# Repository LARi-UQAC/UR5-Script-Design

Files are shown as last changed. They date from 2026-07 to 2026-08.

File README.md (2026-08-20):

# Sponsor
Ask for my book (French version): Vibe Design. 30$ contribution via:





# UR5-Script-Design

Tooling around the ISO/COLIPA cosmetic-spread protocol executed on a Universal Robots
UR5 (PolyScope 3.11.0.82155, CB3 controller) with a RobotIQ FT-300 force/torque sensor
and a 2F-85 gripper holding a silicone hemispheric finger.

Full architecture (package layout, coordinate-frame invariants, extension rules) lives in
[ARCHITECTURE.md](ARCHITECTURE.md). This file is the practical entry point: what the
project does, how to install it, and how to run it.

## What is in this repository

Two cooperating Python tools plus the generated on-robot artifacts:

- **`design/`** - interactive design UI (matplotlib) to tune the 6 spreading cycles
  (3 boustrophedon + epicycloid, 3 linear) on a 50x50 mm plate, then export the
  trajectory as `etalement.script` (URScript) and/or `etalement.urp` (PolyScope XML). A
  Paramètres button opens a settings window covering the protocol's tunable variables;
  operator overrides are kept in `etalement_settings.json` (gitignored, specific to one
  workstation and one trial), with a versioned example at
  `etalement_settings.example.json`. The configuration of the trial of record is a separate,
  versioned file, `etalement_trial.json`, from which `--export-trial` regenerates
  `etalement.script` byte for byte.
- **`ur5_sim/`** - offline validator and replay. Parses `etalement.script`, runs
  sequential IK against a UR5 model, reports failures, and (with `--visualize`) renders
  the robot in Swift (WebGL) alongside matplotlib panels (XYZ vs time, XY trail, IK
  branch selector, test-surface overlay). It can also present itself on loopback as a
  UR5 CB3 RTDE server, so [datalogger/](datalogger/)'s fallback monitor can be exercised
  end to end with no robot present (`--emulate`, headless; `--visualize`, driven by the
  viewer's START / PAUSE / STOP). See [ARCHITECTURE.md](ARCHITECTURE.md), section 8.

## Export options

Today the exporter produces one pair of artifacts:

| File | Content |
|---|---|
| `etalement.script` | URScript program for the real robot: 6 spread cycles, `force_mode(...)` regulating 6 N along Z during contact strokes, no gripper actuation (passive finger support). |
| `etalement.urp` | Same program packaged as PolyScope XML, loadable directly on the pendant. |

`ur5_sim` always validates and replays `etalement.script`; nothing in the simulator
depends on any other export target.

A second, additive export option is planned (tracked in
[issue #6](https://github.com/LARi-UQAC/UR5-Script-Design/issues/6), full design in
[docs/superpower/plans/plan_acq_datalogger.md](docs/superpower/plans/plan_acq_datalogger.md)):
`etalement_acq.script` / `etalement_acq.urp`, the same spread program with a 50 Hz TCP
force/pose data logger attached (background thread on the robot, CSV written to the USB
key once the run completes). It does not replace or modify `etalement.script` /
`etalement.urp`; both pairs will keep being generated side by side, and the simulator
keeps using the plain `etalement.script`.

A second, fully independent fallback tool is **implemented** in
[datalogger/](datalogger/) (issue
[#7](https://github.com/LARi-UQAC/UR5-Script-Design/issues/7), design in
[docs/superpower/plans/plan_rtde_fallback_monitor.md](docs/superpower/plans/plan_rtde_fallback_monitor.md)):
`rtde_fallback_monitor.exe`, a standalone statically compiled C executable run from
`cmd.exe` on a lab computer wired to the same isolated VLAN. It passively reads the
robot's RTDE stream and writes its own CSV with automatic per-run file boundaries, driven
by the `runtime_state` field carried in that same stream (no Python, no PowerShell, no
install of any kind on that machine). It is read-only toward the robot. Neither the main
path nor this fallback depends on the other; build and deployment procedure in
[datalogger/README.md](datalogger/README.md), which also covers testing it locally
against `ur5_sim`'s RTDE emulator, with no lab network and no robot.

## Dependencies

Python 3.13, isolated in a local `.venv` (see [requirements.txt](requirements.txt)):
`numpy`, `scipy`, `matplotlib`, `roboticstoolbox-python`, `spatialmath-python`,
`spatialgeometry`, `swift-sim>=1.1.0`, `websockets<13`, `pyright`, `pip-audit`.

```bash
python -m venv .venv
.venv\Scripts\activate
pip install -r requirements.txt
```

Two pinning constraints to respect (details and file paths in `requirements.txt`):

- `swift-sim==1.1.0` requires `websockets<13`; keep this project's `.venv` isolated from
  any global environment that needs `websockets>=13` (for example an LLM SDK).
- `roboticstoolbox-python==1.1.1` on Python 3.13 with `numpy>=2` needs two small in-place
  patches (`DistanceTransformPlanner.py`, `xacro/xmlutils.py`), and `swift-sim` on
  Windows needs a local patch to its `/retrieve/<path>` handler so UR5 meshes load in
  the browser. Apply once after `pip install`; see the header comment of
  `requirements.txt` for the exact patch locations.

Validate the installed dependencies with `pip-audit -r requirements.txt` before any
release.

## Starting the software

Quickest path on Windows, an interactive menu that activates `.venv` automatically:

```bash
.\validate.bat
```

Menu options: kinematic check (target or identity anchor), 3D visualizer (Swift +
matplotlib), design UI alone, design UI and viewer started together, or (options 7-8)
the RTDE emulator alone with the fallback monitor, and a check of its recorded CSV.
Options 3-4 and 7 also start `datalogger/rtde_fallback_monitor.exe` in its own window
when the `.exe` has been built, so a trial run can be cross-checked against the same
loopback stream with no extra step.

Equivalent manual commands:

```bash
# Offline check (parse + IK, no GUI)
python -m ur5_sim --check

# Full visualizer (Swift 3D + matplotlib panels; RTDE emulator served by default)
python -m ur5_sim --visualize
python -m ur5_sim --visualize --no-rtde-serve   # without the emulator socket

# RTDE emulator alone, headless, no GUI and no robot (see ARCHITECTURE.md section 8)
python -m ur5_sim --emulate --runs 2 --pause-at 30
python -m ur5_sim --verify-csv auto             # check the newest recorded CSV

# Design UI (also re-exports etalement.script and .urp)
python ur5_etalementv6.py
python ur5_etalementv6.py --export        # write etalement.script
python ur5_etalementv6.py --export-urp    # write etalement.urp
python ur5_etalementv6.py --no-show       # headless
python ur5_etalementv6.py --export --force  # overwrite a hand-edited output file
python ur5_etalementv6.py --export-trial --no-show --force
                                          # regenerate the trial of record
```

The design window's Paramètres button opens the settings editor described below. The
Sortie field next to Exporter URScript names the output file (default `etalement`), so a
trial variant can be produced without touching the reference `etalement.script`. Settings
persist to `etalement_settings.json` at the repo root (gitignored, specific to one
workstation and one trial); a versioned example lives at
`etalement_settings.example.json`. Both `--export` and `--export-urp` (and the equivalent
Enregistrer/Exporter buttons in the settings window) refuse to overwrite an output file
whose content has drifted from the last recorded export - a `.urp` retouched by hand on
the pendant, for instance - unless `--force` is passed.

Every generated file opens with a "RECETTE DE REPRODUCTION" header stating what produced
it: how many cycles, and for each one its type, its waypoint count and its label, then any
setting that differs from the `design/params.py` defaults, then a short fingerprint. The
header deliberately carries no date. A timestamp would make each export differ from the
last for no reason anyone cares about, and git already records when a file changed; what
was missing was what the file was made of.

The committed `etalement.script` is the trial of record, the program that ran on the robot.
It comes from the interface export path rather than the headless one, and the configuration
that produced it is written down in the versioned `etalement_trial.json`, so
`--export-trial` reproduces it byte for byte. Do not confuse that file with
`etalement_settings.json`, which holds one workstation's overrides and stays gitignored.

## Settings

The Paramètres button opens a window with five tabs, generated from a single metadata
table so a new field never needs its own hand-written row: Force (target Z force and the
`force_mode` deviation limits), Sondage (Z-probe timing, plus the parked 3-point probe
fields), Mouvement (URScript accelerations, phase speeds, blend radius, circular waypoint
density), Surface (plate size, transit and retreat heights, cycle durations and counts),
and Calibration (robot origin, base rotation, `P_REF`, and the four TCP tool-length
offsets). Each row shows the field next to its hard-coded default and valid range, so a
saved override stays legible against the protocol reference in `design/params.py`.

Two fields stay read-only on every tab: `urscript_max_tcp_speed` and `urscript_max_bytes`
are PolyScope controller limits, not preferences, and letting the operator edit them would
misrepresent what the real controller enforces. The Calibration tab is locked behind an
explicit "Deverrouiller la calibration" checkbox with a confirmation dialog, because its
fields move the robot's anchor in the world rather than tune the spreading protocol; a
session always reopens locked, since nothing there is meant to persist by accident.
`tcp_z` is
computed from the four tool-length fields above it (FT-300, coupling, 2F-85 gripper,
silicone finger) and cannot be edited on its own.

The Sondage tab's dropdown still lists a `plane3` probing mode, but `validate()` refuses
that value when Appliquer is clicked, and the four fields `plane3` alone would need
(approach height, tilt limit, retry count, probe points) stay grayed out regardless of the
selected mode: the 3-point probe is parked, incorrect as implemented (fixed in Z, no
tilt), and its rework is separate future work (see [ARCHITECTURE.md](ARCHITECTURE.md),
section 6).

Réinitialiser resets either the current tab or the whole window to the `design/params.py`
defaults. Deleting `etalement_settings.json` has the same effect for the whole file: the
settings layer falls back to those defaults whenever the file is absent or unreadable.

## Tests

Stdlib `unittest`, no pytest:

```bash
python -m unittest discover -s tests -p "test_*.py"
```

Among that suite, `test_force_model.py`, `test_rtde_server.py`, `test_rtde_headless.py`,
`test_emulate_cli.py`, `test_viewer_rtde_wiring.py` and `test_verify_csv.py` cover the
RTDE emulator - loopback only, GUI-free, no robot needed. Full detail in
[ARCHITECTURE.md](ARCHITECTURE.md), section 10.

One exception, in C: the RTDE fallback monitor in [datalogger/](datalogger/) is a C tool,
because the lab computer it runs on has no Python and nothing can be installed there. Its
tests are C as well, so they call the tool's own functions directly instead of shelling
out, and they are not collected by the discovery above. Run them with MinGW-w64 `gcc` on
`PATH`:

```bash
datalogger\tests\build_and_run_tests.bat
```

## Where to go next

- [ARCHITECTURE.md](ARCHITECTURE.md) for the package layout, the three coordinate
  frames every new pose must travel through, the CB3 URScript generation constraints,
  the force-mode kinematic surrogate, and the rules for extending the project.
- [CLAUDE.md](CLAUDE.md) for the same material kept as an operational summary.

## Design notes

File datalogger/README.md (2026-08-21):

# datalogger

Data-acquisition tooling for the ISO/COLIPA cosmetic-spread trials on the UR5 CB3.

Two independent paths record the same variables. Both are required; neither replaces the
other, and they share no code, no process and no file, so a fault in one cannot corrupt the
output of the other.

| Path | Where it runs | Output | Status |
|---|---|---|---|
| On-robot logger (main) | Robot controller + USB key | `ACQ_log_*.csv` | Implemented, in [`../onrobot/`](../onrobot/README.md) - Python, not part of this folder |
| RTDE fallback monitor | Lab computer, over the network | `ACQ_rtde_*.csv` | Implemented, described below |

**This folder is C only.** It holds one executable, which records what the robot transmits
on its RTDE port, plus its build script and its C test harness. The on-robot acquisition
path is Python and lives in [`../onrobot/`](../onrobot/README.md); the two share the seven
CSV columns and nothing else - no code, no process, no file.

---

## RTDE fallback monitor

`rtde_fallback_monitor.exe` reads the robot's Real-Time Data Exchange stream from a second
machine and writes one CSV per robot program run. It touches nothing on the controller: no
URScript program, no USB key, no installed software. Design and rationale are in
[`plan_rtde_fallback_monitor.md`](../docs/superpower/plans/plan_rtde_fallback_monitor.md).

The tool is **read-only toward the robot**. It opens one outbound TCP connection, requests
an output recipe and reads packets. The RTDE input path is never used, so no motion
command, no register write and nothing else that could disturb a running program can leave
this tool. It is safe to leave connected during a trial and safe to run at the same time as
the on-robot logger, which is how the two sources cross-validate each other.

### What it records

`timestamp`, `actual_TCP_pose`, `actual_TCP_force` and `runtime_state`, written as the
seven columns shared with the on-robot path:

```
Time,ForceX,ForceY,ForceZ,PoseX,PoseY,PoseZ
```

Only the translational components are kept (no rotations, no torques), at a 50 Hz cadence.

### Automatic file boundaries, no operator action

`runtime_state` travels in the same stream as the measurements, so the tool finds its own
file boundaries with no polling, no second connection and no manual "start a new file"
step:

| Transition | Action |
|---|---|
| `STOPPED` to `PLAYING` | Open a new `ACQ_rtde_*.csv` |
| `PAUSING`, `PAUSED`, `RESUMING` | Nothing: same trial, same file, samples keep appending |
| anything to `STOPPED` | Finalize and close the file |

Starting the tool while a program is already running also opens a file, rather than waiting
for the next program start.

If two trials land in the same wall-clock second, the second file gets a `_1`, `_2` suffix.
No trial can overwrite another: past 99 same-second collisions (bare name plus `_1`
through `_99` all taken), the tool refuses to open a new file rather than reuse one of
those names, and reports the exhaustion on the console.

---

## Build

Needs MinGW-w64 `gcc` (`x86_64-w64-mingw32`). Build on any normal networked machine; the
lab computer needs nothing installed.

```
datalogger\build.bat
```

or directly:

```
gcc -O2 -static -Wall -Wextra -o rtde_fallback_monitor.exe rtde_fallback_monitor.c -lws2_32
```

`-static` links the MinGW C runtime in, so the result is a single self-contained 64-bit
executable. Confirmed dependencies are `KERNEL32.dll`, `msvcrt.dll` and `WS2_32.dll` only,
all core Windows libraries present on every Windows 10 install.

## Test

```
datalogger\tests\build_and_run_tests.bat
```

Builds and runs the harness (283 checks; non-zero exit on any failure). No robot, no
network, no framework. It covers big-endian decoding against known byte sequences, every
ordered `runtime_state` transition pair, the decimation cadence, the CSV format, and an
integration layer that replays the RTDE handshake from a fake server on `127.0.0.1`:
one-run/one-file, pause not splitting a file, two runs producing two files, a reset
connection leaving the partial file intact, a `NOT_FOUND` recipe field aborting before any
data is logged, and the protocol-version-1 fallback.

Run it before any on-robot step.

```
datalogger\tests\build_and_run_tests.bat --repeat 20
```

Builds once, then runs the harness 20 times and requires every run to produce the same exit
code and the same summary line as the first; this is how the fake server's handshake is
checked to be deterministic (F16), rather than merely passing once. A run that diverges has
its full stdout kept as `mismatch_run_<N>.out` next to the harness, named on the console:
without it the gate would report that something differed and then delete the only record of
what it was. Those files are gitignored and are deleted at the start of the next
`--repeat` run.

---

## Testing locally against `ur5_sim`

Before wiring the VLAN and the real robot, the whole socket path can be exercised on one
development machine, loopback only, with no robot present: `ur5_sim` (design in
[`plan_rtde_emulator.md`](../docs/superpower/plans/plan_rtde_emulator.md)) can present
itself as a UR5 CB3 RTDE server on `127.0.0.1:30004`, the same handshake, recipe and byte
layout this monitor expects from the real controller. See
[ARCHITECTURE.md](../ARCHITECTURE.md), section 8, for the full wire contract.

Two terminals, no VLAN, no static IP (both from the repo root):

```
# Terminal 1 - the monitor, pointed at loopback instead of the robot; sim_runs is
# where --verify-csv auto looks first
datalogger\rtde_fallback_monitor.exe 127.0.0.1 30004 datalogger\sim_runs

# Terminal 2 - the emulator, headless, two consecutive runs
python -m ur5_sim --emulate --runs 2
```

`ur5_sim --visualize` also serves the emulator by default, driven from the viewer's
START / PAUSE / STOP instead of `--runs`; pass `--no-rtde-serve` to turn it off.
`.\validate.bat` wraps both terminals into one step: options 3, 4 and 7 start the monitor
automatically (skipped with a warning if `rtde_fallback_monitor.exe` has not been built
yet), and option 8 runs `python -m ur5_sim --verify-csv auto` against whatever the monitor
just recorded, in `datalogger\sim_runs\`.

A CSV recorded from the emulator is not a lab trial, and its header says so: any peer
connecting from a loopback address gets a `# WARNING: SIMULATED SOURCE - ur5_sim RTDE
emulator, not robot data` line, right after `Robot RTDE Endpoint`, so a loopback recording
can never be mistaken for one filed from the real UR5 at `192.168.4.38`. `--verify-csv`
reads the same header and echoes the note back in its own report.

---

## Deployment procedure

1. **Build** on a machine that has `gcc` (need not be the lab computer): `build.bat`.
2. **Wire** the lab computer to IE5000 switch port 4 (VLAN 4). Wired only: the site's
   `laimi-robot` Wi-Fi conflicts with other local networks and is not a supported path.
3. **Set the static IP** `192.168.4.14/24` on that interface. There is no DHCP on this
   VLAN.
4. **Confirm the subnet mask** against the switch's VLAN 4 configuration. `/24` is the
   working assumption, consistent with both addresses, but it was never confirmed against
   the switch; adjust the prefix length if VLAN 4 uses something else.
5. **Confirm reachability** before touching RTDE:
   ```
   ping 192.168.4.38
   ```
6. **Copy only** `rtde_fallback_monitor.exe` to the lab computer. Nothing else ships: no
   DLL, no installer, no source.
7. **Run it** from `cmd.exe`, from the folder where the CSVs should land:
   ```
   rtde_fallback_monitor.exe 192.168.4.38 30004 .
   ```
   Stop it with Ctrl+C; the file in progress is finalized before it exits.

### First-run SmartScreen prompt

An unsigned executable copied from removable media raises "Windows protected your PC" the
first time it runs. Click **More info**, then **Run anyway**. This is expected once, not a
failure to debug.

## Verifying on the robot

1. Start a trial from the pendant. An `ACQ_rtde_*.csv` appears on its own, with no action on
   the lab computer.
2. Pause and resume from the pendant mid-trial. The file must **not** split in two.
3. Stop the trial. The file closes; the console prints its row count.
4. Start a second trial. A second, distinct file opens automatically.
5. If the on-robot path is also running, confirm both CSVs are plausible and independently
   readable for the same trial. The two sample independently, so this is a cross-check, not
   an equality test.

On the first connection the tool prints the measured inter-packet interval, for example:

```
[RTDE] stream interval 0.0080 s (125.0 Hz), decimating to 50 Hz
```

That line settles the controller's real base output rate, which is not confirmed from
public documentation for this PolyScope build.

---

## CSV format

```
# Robot Model: UR5 CB3
# PolyScope Version: 3.11.0.82155 (20 August 2019)
# Data Source: RTDE fallback monitor (192.168.4.14)
# Robot RTDE Endpoint: 192.168.4.38:30004
# File Creation Date: 2026-08-14
# File Creation Time: 10:15:30
# Target Acquisition Frequency: 50 Hz
# Time Column: RTDE timestamp field, relative to the first sample of this file (s)
# RTDE Timestamp At First Sample: 123456.797000 s (controller uptime)
Time,ForceX,ForceY,ForceZ,PoseX,PoseY,PoseZ
0.000,-0.123456,0.234567,-6.012345,0.412345,-0.298765,0.101234
```

- `Data Source` names the local address of the socket that actually connected to the robot,
  read at run time with `getsockname()`, not a constant: it is `192.168.4.14` above because
  that is the lab computer's static IP from the deployment procedure, but the same binary run
  from a commissioning laptop or the loopback emulator rig names that machine's own address
  instead (`127.0.0.1` on loopback). If the address cannot be read, the field falls back to
  the literal `unknown` rather than a plausible-looking guess. It is independent of
  `Robot RTDE Endpoint` below, which is the peer, always `argv`.
- `Time` is the robot's own RTDE `timestamp`, referenced to the first sample of the file, so
  it starts at `0.000` exactly like the on-robot path's tick time and the two CSVs align
  without any clock conversion. The absolute controller value of that first sample is kept
  in the header, so the offset loses nothing. Three decimals, matching the on-robot path.
- Forces are newtons and poses are metres, six decimals.
- No `Maximum Buffer Size` or `Actual Number of Collected Samples` line: this tool has no
  fixed-size buffer, it streams straight to disk row by row.

### Cadence

The controller streams at its own base rate and the tool imposes the 50 Hz cadence from
each packet's own `timestamp`, so the output is timestamp-exact whatever that base rate
turns out to be. The rule is grid-based, emitting the first packet at or after each 20 ms
boundary. A gap-based rule would give 125/3 = 41.7 Hz on a 125 Hz stream instead of 50 Hz.

## Behavior when things go wrong

| Situation | Behavior |
|---|---|
| Robot unreachable, or not yet powered | Prints the reason, retries every 2 s. Leave it running; it connects when the robot comes up. |
| Controller reboot or cable pull mid-trial | Prints a diagnostic, finalizes the current CSV with every row already written, then reconnects. No truncation, no silent loss. |
| A recipe field unsupported on this build | RTDE answers `NOT_FOUND`; the tool refuses the session and exits rather than decode at wrong offsets and fill a CSV with plausible garbage. |
| Mistyped robot IP | Rejected at startup, before the reconnect loop, so a typo fails fast instead of retrying forever. |

## Notes for maintainers

- **The C source is an exception to this repo's Python-only test convention.** The lab
  computer has no Python and nothing can be installed on it (no internet on that VLAN), so
  the tool is C; its tests are C as well, so they can call its own functions directly rather
  than shell out. They are not part of `python -m unittest discover -s tests`; run
  `datalogger\tests\build_and_run_tests.bat` instead.
- Every multi-byte field is decoded through `read_be_u16` / `read_be_u32` /
  `read_be_double`, never an inline pointer cast. RTDE is big-endian and x86-64 is not; a
  cast would also violate alignment and strict aliasing, since fields sit at arbitrary
  offsets behind a 3-byte header. One place to get right, pinned by known-value tests.
- The tool negotiates RTDE protocol version 2 and falls back to version 1. Version 1 is not
  a degraded mode here: it carries no `output_frequency` field at all, which suits a tool
  that takes whatever the controller streams and imposes its own cadence.
- The tool is standalone. It reads and writes nothing belonging to `etalement.script`,
  `etalement.urp`, `ur5_sim` or the design UI.

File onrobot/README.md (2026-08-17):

# onrobot

The on-controller acquisition path: record TCP force and TCP position at 50 Hz during an
ISO/COLIPA spread trial, one uniquely named CSV per trial, written to the robot's USB key.

Everything here runs without a second machine. The independent fallback path, a C recorder
reading the robot's RTDE stream from a lab computer, is in [`../datalogger/`](../datalogger/README.md);
the two share the seven CSV columns and nothing else - no code, no process, no file - so a
fault in one cannot corrupt the other's output. Design and rationale:
[`plan_acq_datalogger.md`](../docs/superpower/plans/plan_acq_datalogger.md).

| File | Where it runs | Role |
|---|---|---|
| `acq_logger_daemon.py` | Robot controller, from the USB key | Loopback TCP server on port 50100 receiving samples from `etalement_acq.script`, plus an FT-300 reader on port 63351. Buffers in RAM for the whole trial, writes the CSV on `STOP`. |
| `urmagic_acqlogger.sh` | Robot controller, as root | UR magic file: the controller runs it when the key is inserted, it launches the daemon and returns. |
| `acq_emulator.py` | Development machine only | Fake FT-300 plus a fake robot replaying the real poses of `etalement.script`. Never copied to the robot. |

The URScript half is not here: `design/export.py` emits `etalement_acq.script`, the original
6-cycle program plus a `data_logger` thread. The original `etalement.script` is untouched and
remains what `ur5_sim` validates.

## Why the buffer is in the daemon and not in URScript

URScript on a CB3 has no file API, no date function, no `list_append`, no list slicing, and a
practical list size in the hundreds. The 11700-sample buffer and the file write are therefore
impossible in the robot program as originally specified. They live in a Python process on the
same controller; the robot program only opens a socket and sends one list per sample. During
motion there is zero USB I/O.

## Deployment

1. **Copy three files to the root of the USB key**: `acq_logger_daemon.py`,
   `urmagic_acqlogger.sh`, and the exported `etalement_acq.script`. Nothing else. The daemon
   imports only the standard library, so nothing is installed on the controller.
2. **Read `urmagic_acqlogger.sh` before the first insertion.** The controller runs it as
   root. It is short and every line is commented for exactly that reason.
3. **Insert the key** into the pendant. The daemon starts and writes its log beside itself on
   the key. Check that log before trusting a trial: the first FT-300 sample is printed raw,
   which is how a wire-format mismatch is caught before it silently lands in a CSV column.
4. **Load `etalement_acq.script`** in PolyScope and run it. If the daemon is not answering,
   the program aborts with a popup **before the robot moves**.
5. **At the end of the program**, a popup reports `OK ACQ_log_<date>_<time>.csv (N samples)`
   or the daemon's error text. On error the samples stay in the daemon's RAM.
6. **Remove the key only between trials**, never during one.

Each run produces a new timestamped file; a same-second collision appends `_1`, `_2`. No
overwrite is possible.

## CSV

```
# Robot Model: UR5 CB3
# PolyScope Version: 3.11.0.82155 (20 August 2019)
# File Creation Date: YYYY-MM-DD
# File Creation Time: HH:MM:SS
# Target Acquisition Frequency: 50 Hz
# Maximum Buffer Size: 11700
# Actual Number of Collected Samples: N
Time,ForceX,ForceY,ForceZ,PoseX,PoseY,PoseZ
0.016,-0.082475,0.050368,-6.040525,-0.017788,0.586142,0.050004
```

`Time` is robot tick time in seconds, from the controller's own 8 ms thread counter. It steps
0.016 and 0.024 alternately, because 20 ms is 2.5 ticks and cannot be produced exactly: the
thread alternates 2 and 3 ticks for a mean of exactly 20.000 ms. Every sample carries its true
tick time, so the analysis is exact even though the spacing alternates. Forces are newtons,
poses metres, both to 6 decimals. Only collected rows are written.

The same seven columns are produced by the RTDE fallback monitor under the `ACQ_rtde_` prefix,
so two recordings of one trial can be compared directly.

## Protocol on port 50100

| Line received | Daemon action | Reply |
|---|---|---|
| `[t,x,y,z]` or `[t,x,y,z,fx,fy,fz]` | append, merging the latest FT-300 triple when the sample carries no force | none |
| unparsable | counted in `n_bad`, ignored | none |
| `[-1.0,n,0.0,0.0]` | counting sentinel: records what the robot says it sent | none |
| `STOP` | write the CSV, fsync, close | `OK <file> <rows>` |
| `STOP` after a write failure | keep the buffer in RAM | `ERR <reason>` |
| `RETRY` | rewrite from the retained buffer | `OK ...` or `ERR ...` |

The sentinel exists because a CB3 cannot build the string `STOP <n>`: PolyScope 3.x has
neither `to_str` nor `str_cat`. The count arrives as a list whose first field is negative,
which no real sample can be, immediately before the literal `STOP`. A disagreement between
that count and the rows received is reported, never corrected: it is the only evidence
available that lines were lost.

## Offline exercise, no robot

Three shells:

```
python onrobot/acq_logger_daemon.py
python onrobot/acq_emulator.py --ft
python onrobot/acq_emulator.py --robot etalement.script --samples 200
```

The third replays the real poses of the exported program at 50 Hz with the same alternating
tick times, ends with the sentinel and `STOP`, and exits non-zero unless the daemon answers
`OK`. `--samples` exercises the buffer cap without waiting four minutes.

## Tests

```
python -m unittest tests.test_acq_logger_daemon -v   # 30 tests, daemon
python -m unittest tests.test_acq_export -v          # 13 tests, emitted script
```

Both are collected by `python -m unittest discover -s tests -p "test_*.py"`, unlike the C
harness of `../datalogger/`. They run offline on Windows: fake sockets, a fake clock, a temp
directory standing in for the USB key. `test_acq_export.py` is the one that matters most for
safety - it proves the acq twin's motion is identical to the original's, pose for pose.

## Known limitations

- **`RETRY` recovers only within the same connection.** If the socket drops before `STOP`,
  the buffered trial is lost with it.
- **The FT-300 wire format is not confirmed** from public documentation for URCap 1.11.0.29.
  The parser follows the documented Robotiq format and the daemon logs one raw sample at
  connect time so a mismatch is visible rather than silently miscolumned.
- **Force and pose are merged, not simultaneous.** The FT-300 streams at 100 Hz and its
  latest triple is attached to each 50 Hz pose, so the worst-case skew is 10 ms.
- **No USB mount detected** falls back to `/tmp` with a warning in the metadata rather than
  losing the trial. The mount point varies across CB3 images, which is why it is detected
  from `/proc/mounts` instead of hardcoded.
- **The controller clock may be wrong** on an isolated network with no NTP. Filenames stay
  unique regardless; only the absolute date is affected.

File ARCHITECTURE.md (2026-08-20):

# Architecture — UR5Script

Reference architecture for the ISO/COLIPA cosmetic-spread tooling (UR5 + RobotIQ FT-300 +
2F-85 holding a silicone hemispheric finger). This file is the context base for the next
improvement: it states what exists, which invariants must survive any change, and where
new work plugs in. It supersedes the older module descriptions in `CLAUDE.md` where they
disagree (the design UI is now the `design/` package; IPC is now UDP).

## 1. System overview

Two cooperating Python tools plus the generated on-robot artifacts:

```mermaid
flowchart LR
    subgraph design["design/ (trajectory design UI)"]
        params[params.py<br/>single source of truth]
        geometry[geometry.py<br/>SE3 + plate_to_robot]
        trajectory[trajectory.py<br/>cycle generators]
        export[export.py<br/>URScript / URP emit]
        app[app.py<br/>matplotlib UI]
        liveipc[live_ipc.py<br/>UDP receiver + overlay]
    end

    subgraph artifacts["Exported artifacts"]
        script[etalement.script<br/>URScript CB3]
        urp[etalement.urp<br/>PolyScope XML]
    end

    subgraph sim["ur5_sim/ (offline validator + replay)"]
        parsing[parsing/urscript.py]
        kin[kinematics/<br/>transforms, ik, ik_multisolve, motion]
        surf[visualization/surface.py<br/>force-mode surrogate]
        viewer[visualization/viewer.py<br/>Swift + matplotlib]
        report[reporting/text_report.py]
        cli[cli.py]
        probe[probe.py<br/>PARKED 3-point probe]
    end

    robot[UR5 CB3 controller<br/>force_mode 6 N on Z]

    app --> export
    export --> script
    export --> urp
    script --> robot
    urp --> robot
    script --> parsing
    parsing --> cli
    cli --> kin
    cli --> surf
    cli --> report
    cli --> viewer
    viewer -- "UDP 127.0.0.1:47811<br/>JSON frame" --> liveipc
    params -.imported by.-> geometry
    params -.imported by.-> simconfig[ur5_sim/config.py]
```

- `design/` is the interactive design UI (entry point kept as `ur5_etalementv6.py`, a
  2-line shim over `design.app.main`). The operator tunes the 6 spreading cycles
  (3 boustrophedon + epicycloid, 3 linear) on a 50x50 mm plate and exports
  `etalement.script` / `etalement.urp`.
- `ur5_sim/` parses the exported URScript, replays it through sequential IK against
  `roboticstoolbox.models.UR5`, applies a kinematic surrogate of the force mode, and
  reports failures (`--check`) or renders the run (`--visualize`, Swift WebGL +
  matplotlib panels).
- The real robot regulates 6 N along Z with `force_mode(...)` during contact strokes;
  the simulator has no physics and emulates this geometrically (section 5).

## 2. Package layout and responsibilities

### `design/` — trajectory design

| Module | Responsibility |
|---|---|
| `params.py` | Hard-coded protocol defaults, versioned, never written by the UI. `design/settings.py` reads each field's default from here; `ur5_sim/config.py` imports the shared subset, never redefines a constant downstream. |
| `settings.py` | `Settings` dataclass: the effective values read at runtime by the exporter, the UI, and the simulator. Loads overrides from `etalement_settings.json` (`from_file`), writes only the fields that differ from `params.py` (`to_overrides`, `save`), resets to defaults (`reset`), validates bounds and TCP-speed clamps (`validate`, `clamps`, `clamped`), flags physically dubious combinations (`warnings`), and exposes the process-wide singleton (`get_settings`, `reload_settings`, `set_settings`) plus `startup_banner()` for the CLI. |
| `settings_spec.py` | One `FieldSpec` per exposed setting: label, unit, bounds, tab group, and the three flags that decide editability - `editable` (hard read-only, e.g. controller limits), `locked` (needs the Calibration unlock), `enabled` (grayed out, e.g. the parked `plane3` fields). `settings.py` and the UI both read `SPECS` instead of repeating per-field code. |
| `geometry.py` | SE(3) primitives and the `plate_to_robot()` / `_abs_pose()` frame conversions; reads calibration fields through `get_settings()` at call time rather than importing them by value. |
| `trajectory.py` | Cycle generators (`circular_cycle`, `linear_cycle`, `triangular_cycle`) in the plate frame (mm); also read through `get_settings()` at call time. Hosts `resample_points()`, which used to live in `app.py`: regenerating a trial headlessly needs it, and importing the UI to get it would pull matplotlib and its backend. |
| `trial_config.py` | Replays the trial of record described by the versioned `etalement_trial.json` without any UI: `load_trial_config()`, `trial_settings()` (the trial's own overrides, deliberately independent of the workstation's `etalement_settings.json`), and `build_trial_cycles()`. Reached from the CLI as `--export-trial`. This is what makes the committed `etalement.script` regenerable byte for byte rather than an artifact nobody can reproduce (F10). |
| `export.py` | Emits `etalement.script` and `etalement.urp`, reading `Settings` at call time in `_build_urscript_lines()` instead of importing constants by value; prepends a `# === RECETTE DE REPRODUCTION ===` block to EVERY export (`_recipe_header_lines`), naming the cycle count, each cycle's type, waypoint count and label, then the deviations from defaults (`_settings_header_lines`, the only conditional part) and the settings fingerprint. The block carries no date: a timestamp is what made an export non-reproducible, which had forced the block to be emitted only on deviation, leaving the commonest export recording nothing (F10). Owns the CB3 constraints, the PolyScope memory budget check, and the TCP speed clamp. `generate_urscript()` / `generate_urp()` take a `settings=` override and a `force=` flag: `check_overwrite()` compares the output file's digest against `.etalement_export_state.json` (the record of the last export) and refuses to overwrite a hand-edited file unless `force=True`. The program never actuates the 2F-85 (passive finger support: no `rq_*`, no `set_payload`, no tool RS485). |
| `ui_settings.py` | `open_settings_window()` and the `SettingsWindow` Toplevel: five `ttk.Notebook` tabs generated from `settings_spec.SPECS`. Tolerant of a Tk-less environment - returns `None` and prints a message, never raises. |
| `ui_widgets.py` | Widget construction, text/value conversion, and the body of `apply()` / `reset()` / `save()` / `export()`, kept out of `ui_settings.py` so both files stay under the 4096-token ceiling (`.claude/rules/code-style.md`). |
| `live_ipc.py` | Non-blocking UDP receiver drained on each matplotlib timer tick; converts world-m poses back to plate-mm via the inverse of `plate_to_robot()` and draws the live TCP star + trail on the matching cycle subplot. |
| `app.py` | matplotlib UI, widget wiring, `main()` entry point (`--export`, `--export-urp`, `--export-trial`, `--no-show`, `--force`). The discretization and cycle-shape sliders are views onto `Settings` rather than separate state; the Paramètres button opens `ui_settings.open_settings_window()`. |

### `ur5_sim/` — validation and replay

| Layer | Responsibility |
|---|---|
| `parsing/urscript.py` | Lenient regex reader. `parse_poses()` returns 4-tuples `(lineno, pose, cycle_idx, in_contact)`; handles three emit formats (`movel(T(p[...]))` legacy, `movel(apply_correction(p[...], dx, dy))` current, plain `movel(p[...])`). `force_mode` / `end_force_mode` toggle `in_contact` inside each `def cycle_N():`. Also parses probe blocks, `NHAT`, the nominal frame, and `global <NAME> = <speed>` preamble declarations. |
| `kinematics/` | `transforms.rotate_translation_y` is the only implementation of the `SIM_TRAJ_ROT_Y_RAD` remap (currently 0.0 since `P_REF` has identity orientation). `ik.run_ik` (sequential IK on link `tool0`), `ik_multisolve` (branch enumeration), `motion.densify_segments`. |
| `visualization/` | Split by concern so no file passes the 4096-token ceiling (F6). `viewer.py` is the assembly point: it normalises the per-frame lists, builds the scene and the figure, wires the widgets, and hands control to `plt.show()`. `swift_scene.py` (3D scene: launch, meshes, WebSocket keepalive, per-frame pose push, tab reopen, teardown), `mpl_display.py` (figure, panels, plate and probe overlays, widgets, per-frame artist repaint), `playback.py` (trajectory buffer, wall clock, HUD, the matplotlib timer callback), `controls.py` (START / STOP / configuration callbacks), `playback_clock.py` (`PlaybackClock`, the START/PAUSE/STOP timing rule, unit-tested), `recompute.py` (off-GUI-thread re-parse and IK), `ipc_live.py` (UDP loopback status feed; `send_tcp_live` stays importable from `swift_scene`), `rtde_link.py` (the RTDE emulator's `load()` / `publish()` hooks, called once per frame and no-ops when no server is served; maps START/PAUSE/RESUME/STOP onto the monitor's PLAYING/PAUSING/PAUSED/STOPPED file boundaries, section 8), `surface.py` (plate geometry + force surrogate, reads calibration and force fields through `get_settings()` at call time rather than at import), `interactions.py` (mouse pan/zoom on the XY panel). |
| `meshes/` | FT-300 + 2F-85 + `Support doigt.stl` pipeline for Swift: decimation, color extraction, link loader. |
| `reporting/text_report.py` | Prints surface events first (`SURFACE_DEVIATION` / `SURFACE_CLAMP`), then IK / joint-limit failures. |
| `cli.py` | Argparse entry (`--check`, `--visualize`, `--identity`); prints `config.settings_summary()` at the head of every report (source, read timestamp, overrides) before anchoring `P_ANCHOR_OLD` / `P_REF`, applying the surface constraint pre-IK, filtering expected recontact deviations (section 5), and checking TCP speed globals against `URSCRIPT_MAX_TCP_SPEED_MPS`. |
| `emulate.py` | CLI side of the RTDE emulator (section 8): the `--rtde-serve` / `--no-rtde-serve` / `--rtde-port` / `--emulate` / `--runs` / `--pause-at` flags, `wants_rtde()` (on by default with `--visualize`, refused with a printed reason on `--check`), `build_rtde_server()` (wires `ForceModel` into `RtdeServer`), and the SE3 -> `(x, y, z, rx, ry, rz)` / penetration buffer conversions the server is fed. |
| `rtde_server.py` | `RtdeServer`: one loopback client, the CB3 handshake, and a 125 Hz emitter thread (section 8). Output packages only, so nothing that connects can command it. Re-exports `rtde_wire.py` (framing, recipe, `RunStateMachine`, trajectory interpolation) and `rtde_headless.run_headless`, split out only to hold the file-size ceiling. |
| `force_model.py` | `ForceModel`, the FT-300 surrogate driving `actual_TCP_force`: contact regulation, Coulomb friction, sensor noise, from the contact flag, penetration depth and TCP velocity. Parameters are **plausible, not measured** (`config.py` `FORCE_MODEL_*`). |
| `verify_csv.py` | `--verify-csv` glue: geometric distance from each recorded point to the commanded, surface-clamped polyline (survives a pause, unlike a time-indexed check), the newest-`ACQ_rtde_*.csv` lookup, and the report printer (section 8). |
| `config.py` | Paths, anchors, sim DT/speed, surface constants, mesh decimation targets. Reads `etalement_settings.json` through `design.settings.get_settings()` once at import - the same file the UI writes - and falls back to `design/params.py` defaults when it is absent; `settings_summary()` reports the source and the read time, since a run in progress while the operator saves new settings still validates against the old ones. Shared constants otherwise imported from `design.params`, not duplicated. |
| `ipc_config.py` | UDP host/port/payload constants shared by writer (viewer) and reader (design UI). |
| `probe.py` | 3-point probe simulation. **Parked** (see section 6). |

### `datalogger/` and `onrobot/` — trial data acquisition, two independent paths

Two tools record the same seven columns during a trial. Both are required and neither
replaces the other; they share no code, no process and no file, so a fault in one cannot
corrupt the other's output. This folder is the one place in the repository where the
language is not Python by default: see the invariant in section 9.

| File | Responsibility |
|---|---|
| `datalogger/rtde_fallback_monitor.c` | Fallback path. Standalone C executable running on a lab computer, reading the robot's RTDE stream over the network (port 30004) and writing one `ACQ_rtde_*.csv` per program run. Read-only toward the robot: it opens one outbound connection and never uses the RTDE input path, so it is safe to leave connected during a trial. Its test harness (`tests/`, 283 checks, run through `tests/build_and_run_tests.bat`) includes a fake RTDE server on loopback, so the whole socket path runs with no robot. |
| `onrobot/acq_logger_daemon.py` | Main path, on the controller. Loopback TCP server on port 50100 that the `data_logger` thread of `etalement_acq.script` streams samples into, plus an `FTReader` thread merging the Robotiq FT-300 stream from the fixed port 63351. Buffers in RAM for the whole trial (zero USB I/O while the robot moves), then writes `ACQ_log_YYYYMMDD_HHMMSS.csv` to the detected USB mount on `STOP`, fsyncs it, and replies `OK <file> <n>` or `ERR <reason>`. |
| `onrobot/urmagic_acqlogger.sh` | UR "magic file": run as root by the controller when the USB key is inserted, it launches the daemon from that same key and returns immediately. |
| `onrobot/acq_emulator.py` | Development machine only. Fake FT-300 server plus a fake robot client replaying the real poses of `etalement.script` into the daemon at 50 Hz, so the whole acquisition path runs offline. The acquisition-side mirror of the C fake RTDE server. |

The URScript side is emitted by `design/export.py`: `_build_acq_lines()` wraps the untouched
output of `_build_urscript_lines()` with the logger thread and the STOP handshake, and
`generate_urscript_acq()` / `generate_urp_acq()` write the `etalement_acq.*` twins. The
simulator never reads them; `tests/test_acq_export.py` proves the twin's motion is identical
to the original's, pose for pose.

## 3. Coordinate frames — the invariant chain

Three frames are always in play; every pose and every piece of geometry must travel the
same chain or it lands in the wrong frame.

1. **Plate frame** (mm, +Z out of the plate) - `design/params.py` (`SURFACE_W/H`,
   `Z_CONTACT`, `Z_TRANSIT`, `Z_RETREAT_END`). All trajectory generators work here.
2. **Robot base frame** (m) - `plate_to_robot()` rotates by
   `ROBOT_BASE_ROTATION_DEG = 225` around the plate origin, translates by
   `ROBOT_X_ORIGIN` / `ROBOT_Y_ORIGIN`, and sets `Z = ROBOT_Z_SURFACE` for the contact
   plane.
3. **Absolute world frame** (m) - `_abs_pose()` pre-bakes
   `pose_trans(P_REF, pose_trans(pose_inv(P_ANCHOR_OLD), p_orig))`. The exported script
   carries absolute poses directly (no `T(...)` wrapper). `cli.py` still composes
   `transform(p, P_ANCHOR_OLD, P_REF)` on every parsed pose, then
   `rotate_translation_y(_, SIM_TRAJ_ROT_Y_RAD)`.

Canonical recipe for adding any new geometry (fixture, tool tip, marker):
`plate_to_robot` -> `_abs_pose` -> `transform` -> `rotate_translation_y`, exactly as
`ur5_sim/visualization/surface._plate_corner_world` does.

Tool offset: IK targets `tool0` (rtb flange frame, already including the 82.3 mm wrist
offset); the TCP sits `TCP_TOOL_Z_M` further along tool0 Z, mirrored on-robot by
`set_tcp(...)` so simulator and controller agree.

## 4. URScript generation constraints (CB3 / PolyScope 3.x)

`export.py` targets a CB3 controller. Hard constraints baked into the emitter:

- No `stopl` and no `movel` inside URScript threads.
- No list slicing (`[0:3]`) - CB3 URScript lacks it.
- PolyScope program memory budget checked by `_validate_script_memory()`.
- TCP speed capped at `URSCRIPT_MAX_TCP_SPEED` by `_clamp_tcp_speed()`; the simulator
  re-reads the declared speed globals and flags any excess (real controller would
  safety-stop).
- Contact strokes wrapped in `force_mode(...)` / `end_force_mode()` with
  `FORCE_Z_TARGET` (6 N) along Z.
- Program ends with a pure retreat (`Z_RETREAT_END`, out of force mode) so the operator
  can remove the plate.

## 5. Force-mode kinematic surrogate

No physics layer. `ur5_sim/visualization/surface.apply_surface_constraint` emulates the
6 N regulation, running in `cli.py` **before** `run_ik` so IK receives feasible targets:

- `in_contact = True`: TCP target snapped bidirectionally onto the surface plane;
  pre-snap deviation beyond `CONTACT_SNAP_TOL_M` logged as `SURFACE_DEVIATION` (signed mm).
- `in_contact = False`: clamped from below only; penetration logged as `SURFACE_CLAMP`.
- The recontact descents deliberately target `FORCE_CONTACT_DEPTH` (5 mm) below the
  nominal plane (the real robot stops at contact); `cli.py` filters `SURFACE_DEVIATION`
  events within `SURFACE_FORCE_TARGET_TOL_M` of that depth to avoid one spurious event
  per cycle.
- Toggle: `SURFACE_ENABLE_CLAMP`. `FORCE_Z_TARGET_N` is HUD-label only in sim.

## 6. Surface probing — current state and parked rework

- **Active**: 1-point Z probe (`probe_surface_z`) emitted by `export.py`. Measures the
  plate height only.
- **Parked**: the 3-point probe (`probe_surface_plane`, Rodrigues `MEAS_FRAME`
  reconstruction) proved incorrect - fixed in Z, cannot handle plate rotation or unknown
  plate height. `ur5_sim/probe.py`, its replay in `cli.py` (guarded by
  `SIM_PROBE_ENABLE = False`), and `tests/test_probe_sim.py` are kept inert for a future
  rework, not deleted. Re-enabling means fixing the algorithm first, then flipping the
  flag and un-commenting the tests.

This is the most likely locus of the "next improvement": a correct plane estimation that
handles unknown height and tilt, feeding `apply_correction(p, dx, dy)` (or a full-frame
successor) in the exported script, with a matching geometric replay in `ur5_sim`.

## 7. IPC contract (simulator -> design UI)

UDP unicast on loopback replaces the former `tcp_live/tcp_live.json` atomic-file IPC
(latency ~20-100 us vs 1-10 ms with 50-500 ms tails; drop-tolerant since only the latest
frame matters).

- Constants in `ur5_sim/ipc_config.py`: `127.0.0.1`, port `47811` (override with
  `UR5_SIM_IPC_PORT`), receive buffer 65507 B.
- Writer: `ur5_sim/visualization/viewer.py`, one JSON datagram per frame.
- Reader: `design/live_ipc.py`, non-blocking socket drained per matplotlib timer tick,
  world-m converted back to plate-mm by inverting `plate_to_robot()`.
- Frame keys consumed today: `running`, `cycle`, `frame`, `x_anchor_m` / `y_anchor_m`,
  `trail_anchor_m`. Emitted but not yet consumed: `in_contact`, `force_z_n`,
  `surface_depth_mm` - a ready-made hook for a live force/contact HUD in the design UI.

## 8. RTDE emulation contract (simulator to monitor)

`ur5_sim` can present itself on loopback as a UR5 CB3 RTDE server, so
`datalogger/rtde_fallback_monitor.exe` can be exercised end to end with no robot present.
This is a **separate channel** from section 7's UDP overlay to the design UI - different
protocol (RTDE over TCP vs UDP JSON), different peer (the C monitor vs `design/live_ipc.py`),
different port, no state shared between them - and section 7 is unchanged by its addition.

- **Bind**: `RTDE_EMU_HOST = 127.0.0.1` only (`ur5_sim/config.py`), default port
  `RTDE_EMU_PORT = 30004` (the real controller's port, overridable with `--rtde-port`).
  Binding `0.0.0.0` would make the emulator reachable from the lab VLAN and
  indistinguishable from the robot at `192.168.4.38`; `ur5_sim/emulate.py` offers no host
  flag, so nothing on the command line can widen the bind.
- **Handshake package types** (one byte after a 2-byte big-endian size,
  `RTDE_HEADER_SIZE = 3`): `RTDE_REQUEST_PROTOCOL_VERSION` (86, `'V'`), `RTDE_TEXT_MESSAGE`
  (77, `'M'`), `RTDE_CONTROL_PACKAGE_SETUP_OUTPUTS` (79, `'O'`), `RTDE_DATA_PACKAGE`
  (85, `'U'`), `RTDE_CONTROL_PACKAGE_START` (83, `'S'`).
- **Recipe**: `timestamp,actual_TCP_pose,actual_TCP_force,runtime_state`, typed
  `DOUBLE,VECTOR6D,VECTOR6D,UINT32`.
- **Byte layout** of one data payload (`RTDE_PAYLOAD_SIZE = 108`): `timestamp` at offset 0,
  `actual_TCP_pose` at 8, `actual_TCP_force` at 56, `runtime_state` at 104. There is no
  shared header between the two languages, so `ur5_sim/rtde_wire.py` and
  `datalogger/rtde_fallback_monitor.c` each hard-code these same numbers; they are kept
  honest only by the offset assertions in `tests/test_rtde_server.py` (rule in section 11).
- **`runtime_state` mapping**, the field the monitor keys its file boundaries on
  (`ur5_sim/rtde_wire.RunStateMachine`): `STOPPING` (0), `STOPPED` (1), `PLAYING` (2),
  `PAUSING` (3), `PAUSED` (4), `RESUMING` (5). A transition to `STOPPED` closes the
  monitor's current CSV and the next `PLAYING` opens a new one; `PAUSING` / `PAUSED` /
  `RESUMING` keep the same file growing - the wire-level mirror of the viewer's real PAUSE
  (`ur5_sim/visualization/playback_clock.PlaybackClock`), published by
  `ur5_sim/visualization/rtde_link.py`.
- **Force surrogate**: `ur5_sim/force_model.ForceModel` feeds `actual_TCP_force` from the
  same contact flag and penetration depth as section 5's kinematic surrogate, plus TCP
  velocity. Every parameter (`FORCE_MODEL_STIFFNESS_N_PER_M`, `FORCE_MODEL_TAU_S`,
  `FORCE_MODEL_FRICTION_MU`, `FORCE_MODEL_NOISE_N`, `FORCE_MODEL_SEED` in `config.py`) is
  **plausible, not measured** - output resembles FT-300 data, it is not FT-300 data.
- **Driving it**: `--visualize` serves the emulator by default from the viewer's
  START / PAUSE / STOP; `--no-rtde-serve` turns it off; `--emulate --runs N --pause-at S`
  drives the same state machine headlessly, in real time, with no GUI
  (`ur5_sim/rtde_headless.run_headless`). `--check` never serves: that path has no
  real-time pacing, so a multi-minute protocol would stream in seconds and record nothing
  worth calling a trial; the flag is refused with a printed reason instead of opening a
  socket silently.
- **Verifying a recording**: `--verify-csv [auto|PATH]` (`ur5_sim/verify_csv.py`) checks
  the geometric distance from every recorded point to the commanded, surface-clamped
  polyline rather than a time index, so a paused run is not read as a failure; the
  tolerance is `1e-5` m. A loopback peer gets a `# WARNING: SIMULATED SOURCE` line in the
  monitor's CSV header (`datalogger/rtde_fallback_monitor.c`, `is_loopback_ipv4`), and
  `--verify-csv` echoes that line back in its own report.

## 9. Invariants (do not relax)

### Settings layer

Never `from design.params import X` in a module that must see the operator's overrides.
In Python, `from X import Y` binds the value at import time; a later change to
`design.params.Y`, or to the same field through `etalement_settings.json`, has no effect
on the name already bound in the importing module. The correct form is
`s = get_settings()` followed by `s.<field>` at the point of use, so the read happens
after the current process's settings have been loaded. `design/export.py`,
`design/geometry.py`, `design/trajectory.py`, `design/live_ipc.py`, `ur5_sim/config.py`,
and `ur5_sim/visualization/surface.py` all follow this pattern.

Two categories of constant are exempt and may stay imported by value: paths
(`SCRIPT_PATH`, `URP_PATH`, both derived from `REPO_ROOT`) and constants that are not
exposed in `design/settings_spec.SPECS` at all (`Z_CONTACT`, `LIN_N_PASSES`,
`LIN_N_POINTS_PER_SEGMENT`, `N_LINEAR_CYCLES`, `TCP_X`, `TCP_Y`) - there is no operator
override for the read-at-call-time rule to protect. The `ACQ_*` constants added for the
acquisition logger are in that second category on purpose: they are export-time values kept
out of `SPECS`, so no settings fingerprint and no exported header block moves when they are
read by value.

### The acquisition daemon depends on nothing

`onrobot/acq_logger_daemon.py` imports the standard library and nothing else - not
`design`, not `ur5_sim`, not a third-party package. The file is copied **alone** onto a USB
key and must run there, on the controller's Python 2.7, so it is also kept free of
f-strings, type hints and `pathlib`, and it stays a plain module with no `__init__.py`
(tests load it by path with `importlib.util.spec_from_file_location`). It writes its CSV in
binary mode with explicit `\n`, never text mode, so the bytes a Windows test asserts are the
bytes the Linux controller produces.

The dependency runs one way only. `onrobot/acq_emulator.py` is a development tool and may
import `ur5_sim`; the daemon may never be imported by, or import, anything in this
repository. `ur5_sim/force_model.py` (section 8) is the RTDE emulator's force source; it
feeds the emulator's own served stream, never the daemon's behaviour.

### Dependencies

- `swift-sim==1.1.0` needs `websockets<13`; keep this project's `.venv` isolated from
  the global env (Anthropic/Google SDKs need `websockets>=13`).
- `roboticstoolbox-python==1.1.1` on Python 3.13 + numpy>=2 requires the two in-place
  patches documented in `requirements.txt` (`DistanceTransformPlanner.py` numpy import,
  `xacro/xmlutils.py` `_write_data` signature).
- `swift-sim` on Windows needs the local `/retrieve/<path>` drive-letter patch or the
  UR5 meshes 404 in the browser.
- Tests are stdlib `unittest` only; pytest is not installed in `.venv`.

## 10. Tests and validation workflow

```bash
python -m ur5_sim --check                 # parse + IK, no GUI
python -m ur5_sim --visualize             # Swift 3D + matplotlib
python -m ur5_sim --check --identity      # refactor self-check (identity transform)
python ur5_etalementv6.py --export        # regenerate etalement.script
python -m unittest discover -s tests -p "test_*.py"

# RTDE emulator (section 8), against datalogger/rtde_fallback_monitor.exe
python -m ur5_sim --emulate --runs 2 --pause-at 30   # headless, no GUI, no robot
python -m ur5_sim --verify-csv auto                  # newest datalogger/sim_runs/ACQ_rtde_*.csv
```

| Test module | Covers |
|---|---|
| `test_urscript_parse.py` | 4-tuple shape, legacy 3-tuple shim, `force_mode` toggle, `apply_correction` wrapper |
| `test_surface_constraint.py` | `compute_surface_frame`, normal orientation, snap/clamp math, dispatch |
| `test_ik_smoke.py` | first 10 poses end-to-end through IK |
| `test_transforms.py` | SE(3) helpers |
| `test_motion_segments.py` | segment densification |
| `test_limits.py` | joint / speed limits |
| `test_force_target_filter.py` | recontact-depth deviation filtering (section 5) |
| `test_udp_ipc.py` | UDP frame round-trip (section 7) |
| `test_playback_clock.py` | `PlaybackClock`: PAUSE banks elapsed sim time, STOP discards it |
| `test_viewer_pause.py` | the PAUSE control through the real viewer callbacks, headless (Agg + faked `perf_counter`, `env=None`) |
| `test_force_model.py` | `ForceModel`'s stated behaviour (contact regulation, friction, noise), not the realism of its parameters (section 8) |
| `test_rtde_server.py` | the RTDE wire constants pinned against `datalogger/rtde_fallback_monitor.c` (recipe, byte offsets, package types), the served socket and the CB3 handshake (section 8) |
| `test_rtde_headless.py` | `run_headless`: two runs give two STOPPED -> PLAYING edges; a `--pause-at` gives PAUSED with no STOPPED in between |
| `test_emulate_cli.py` | when the emulator opens at all (`--check` never, `--visualize` by default, `--no-rtde-serve` off), that no flag can widen the loopback bind, and the force-surrogate sign convention |
| `test_viewer_rtde_wiring.py` | the viewer publishing START / PAUSE / RESUME / STOP to a recording `RtdeServer` stub, headless (Agg, no socket) |
| `test_verify_csv.py` | the geometric distance-to-polyline check, which survives a pause where a time-indexed comparison would not |
| `test_probe_sim.py` | parked with the 3-point probe (section 6) |
| `test_settings.py` | `Settings.to_overrides` / `from_file` / `save` round-trip, each dataclass default equal to its `design/params.py` constant, and out-of-bounds values rejected with the TCP-speed clamps applied and reported |
| `test_export_settings.py` | `_build_urscript_lines()` at default settings matches `tests/fixtures/golden_headless.script` byte for byte, the recipe block included since it is now deterministic; a changed `Settings` field actually changes the generated script; the recipe block is emitted even at pure defaults and carries no date |
| `test_export_reproducibility.py` | The four checks F10 asks for: the headless export matches the golden fixture, regenerating the trial from `etalement_trial.json` reproduces `etalement.script` byte for byte, the recipe header's announced waypoint counts match the `movel` actually emitted per cycle, and comparing an export against the wrong one of the two references fails with a message naming which is which |
| `test_sim_reads_settings.py` | `ur5_sim/config.py` reflects `etalement_settings.json` when present, falls back to `design/params.py` defaults otherwise |
| `test_settings_persistence.py` | `etalement_settings.example.json` is valid JSON whose overrides name real `SPECS` fields and pass `validate()`; `startup_banner()` is empty at defaults and reports overrides plus the TCP-speed clamp; `etalement_settings.json` is `.gitignore`d |
| `test_ui_settings.py` | Settings-window value capture on an unmapped Tk root, no Playwright and no visible window (section 5.1 of `plan_variables_UI.md`): a valid edit propagates, an out-of-bounds edit is rejected with no field applied, the displayed default matches `design/params.py`, Réinitialiser restores defaults, and read-only or calibration-locked fields refuse edits |

Two reference artifacts coexist, and confusing them is exactly what F10 blamed the repository
for. `tests/fixtures/golden_headless.script` is the headless `_build_urscript_lines()`
output at defaults, subsampled to `URSCRIPT_N_WAYPOINTS_CIRCULAR` and rectilinear on cycles 4
to 6; it is the byte-for-byte identity witness. The committed `etalement.script` is the trial
of record, produced through the interface export path with 200 waypoints per circular cycle
and triangular cycles 4 to 6, and it is regenerated from `etalement_trial.json`. Both were
regenerated on 2026-08-16 when the recipe header landed, in LF, in one deliberate commit
alongside the `CIRC_R_CIRCLE` and `CIRC_N_CIRCLES` default alignment.

No CI: run the suite locally before any change touching parsing, transforms, export, or
the surface module.

## 11. Rules for the next improvement

1. New constants go in `design/params.py`; `ur5_sim/config.py` imports, never redefines.
   A constant exposed to the operator also gets a `FieldSpec` in
   `design/settings_spec.SPECS` and a matching field in `design/settings.Settings`.
2. New geometry travels the full frame chain of section 3 - no shortcuts.
3. Anything emitted into `etalement.script` must respect the CB3 constraints of
   section 4 and get a corresponding parser + replay in `ur5_sim` so `--check` stays a
   faithful pre-flight of the real run.
4. Prefer extending the UDP frame (section 7) over reintroducing file IPC.
5. Never `from design.params import X` in a module that must see operator overrides
   (section 9).
6. The RTDE wire layout (section 8) is duplicated in C and Python by necessity - no
   shared header links them. Any change to the recipe, the byte offsets, or the package
   type values must be made in both `ur5_sim/rtde_wire.py` and
   `datalogger/rtde_fallback_monitor.c` together, and stays pinned by the offset
   assertions in `tests/test_rtde_server.py`; a drift there fails a test instead of
   filling a lab CSV with plausible wrong numbers.

What remains open, in no particular priority order:

- The versioned `etalement.script` / `etalement.urp` were generated from the UI export
  path before the settings layer landed and have not been regenerated against it;
  `circular_waypoint_mode` now makes the subsample-vs-all waypoint-density divergence
  explicit but does not resolve it.
- `URSCRIPT_BLEND_CONTACT` does not exist yet - it belongs to
  `plan_optimisation_urscript.md`, section 5 - so it is not exposed in `SPECS`.
- The parked 3-point probe rework (section 6): correct plane estimation (height and
  tilt), then re-enable `SIM_PROBE_ENABLE` and `test_probe_sim.py`. The `plane3` choice
  is listed in the settings UI but refused by `Settings.validate()`.
- Exposing the Z force as a URScript global editable from the pendant
  (`plan_optimisation_urscript.md`, section 5); today it stays inlined in the
  `force_mode(...)` wrench.
- The settings window's visual rendering is checked by eye by the operator; it is not
  automated (section 5.1 of `plan_variables_UI.md` explains why Playwright was ruled
  out for this window).

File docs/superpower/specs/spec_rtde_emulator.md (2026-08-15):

# Spec — RTDE emulator in `ur5_sim`

Design specification for making `ur5_sim` serve a UR5 CB3 Real-Time Data Exchange stream
on loopback, so the already-built `rtde_fallback_monitor.exe` can be exercised end to end
on a development machine with no robot present.

Matching monitor design: [`../plans/plan_rtde_fallback_monitor.md`](../plans/plan_rtde_fallback_monitor.md).
An implementation plan will follow at `../plans/plan_rtde_emulator.md`.

## 1. Purpose

The RTDE fallback monitor is built and unit-tested, but three of its behaviors can only
be verified with the pendant today (that plan's §6 steps 7-9): a new CSV per program run,
a pause that does not split the file, and two runs producing two distinct files. This
spec moves all three to the desk, and adds something neither existing suite can provide:
the Python encoder and the C decoder become two independent implementations of one wire
format, so their agreement is evidence that both are right.

Secondary purpose, requested explicitly: the emulated stream carries a plausible varying
force profile, so a recorded CSV resembles FT-300 data rather than a two-level square
wave, and can be used to exercise downstream analysis.

## 2. What already exists

- `ur5_sim` parses `etalement.script`, replays it through sequential IK, and applies a
  kinematic surface constraint that yields a per-frame penetration depth
  (`ARCHITECTURE.md` §5).
- `ur5_sim/visualization/viewer.py` already assembles a per-frame telemetry dict carrying
  `in_contact`, `force_z_n` and `surface_depth_mm`, and publishes it as JSON over UDP to
  the design UI (`ARCHITECTURE.md` §7).
- `datalogger/rtde_fallback_monitor.exe` connects out over TCP, performs the RTDE
  handshake, and writes one CSV per robot program run.

Three facts established while designing this spec, each of which constrains it:

1. **The UDP channel cannot serve the monitor.** Different transport (UDP against TCP),
   different encoding (JSON against binary big-endian), and the monitor refuses to log
   until a recipe handshake completes. The emulator is therefore a sibling writer, not a
   modification of `live_ipc.py` / `ipc_config.py`, which keep their existing job.
2. **`DT = 0.05` in `ur5_sim/config.py`** — the trajectory's native resolution is 20 Hz,
   below the 50 Hz the monitor targets. Decimation cannot create samples that were never
   sent, so the emulator must interpolate up to the controller rate. A real CB3 does the
   same between waypoints.
3. **The viewer has no pause.** `set_stop()` is a hard stop ("next START must restart from
   frame 0"), and every path zeroes `paused_sim_t`, a variable that is threaded through
   the clock and never used. A real PAUSE is therefore in scope, since without it the
   pause behavior cannot be tested locally at all.

## 3. Architecture

The emulator owns the run. The viewer hands it the trajectory once, then only reports
state; interpolation, force synthesis, encoding and pacing all happen inside the emitter
thread. The 125 Hz stream therefore never inherits matplotlib's timer jitter, and the
server can be driven by a test with no GUI.

```mermaid
flowchart LR
    subgraph sim["ur5_sim"]
        cli[cli.py<br/>--rtde-serve, --verify-csv]
        viewer[viewer.py<br/>START / PAUSE / STOP]
        surface[visualization/surface.py<br/>penetration depth]
        server[rtde_server.py<br/>TCP + 125 Hz emitter thread]
        force[force_model.py<br/>FT-300 surrogate]
    end
    monitor[rtde_fallback_monitor.exe]
    csv[(datalogger/sim_runs/<br/>ACQ_rtde_*.csv)]

    cli -- "load_run(poses, times, contact, surface)" --> server
    viewer -- "set_run_state(running, sim_time, finished)" --> server
    surface -.penetration.-> force
    force --> server
    server -- "TCP 127.0.0.1:30004<br/>RTDE binary" --> monitor
    monitor --> csv
    csv -- "--verify-csv" --> cli
```

### New modules

| File | Responsibility | Depends on |
|---|---|---|
| `ur5_sim/rtde_server.py` | RTDE wire encoder, TCP server, 125 Hz emitter thread, `runtime_state` machine, pose interpolation. | stdlib only. No matplotlib, no Swift, no spatialmath. |
| `ur5_sim/force_model.py` | FT-300 surrogate: contact regulation, stiffness transient, Coulomb friction, sensor noise. Pure and stateful, no I/O. | stdlib only. |

Both stay well under the 4096-token file ceiling of the workspace `code-style.md`.

`rtde_server.py` receives the trajectory already flattened to plain
`(x, y, z, rx, ry, rz)` float tuples. The SE(3) conversion stays in `cli.py` / `viewer.py`,
which already own the frame chain of `ARCHITECTURE.md` §3. This is the boundary that keeps
the server importable and testable on its own.

### Modified files

| File | Change |
|---|---|
| `ur5_sim/config.py` | `RTDE_EMU_*` and `FORCE_MODEL_*` constants. Sim-only, following the existing `SIM_PROBE_*` precedent; they never reach the exported script, so they do **not** belong in `design/params.py`. |
| `ur5_sim/cli.py` | `--rtde-serve` / `--no-rtde-serve`, `--rtde-port`, `--emulate` (headless paced run), `--verify-csv`. |
| `ur5_sim/visualization/viewer.py` | PAUSE control; one `set_run_state(...)` call beside the existing UDP emit; server start/stop around the animation. |
| `datalogger/rtde_fallback_monitor.c` | Loopback provenance warning in the CSV header. |
| `validate.bat` | Start the monitor alongside the visualizer; two new menu entries. |
| `ARCHITECTURE.md`, `README.md`, `CLAUDE.md`, `datalogger/README.md` | Documentation, see §12. |

## 4. Wire contract (shared with the C monitor)

The emulator implements the server side of exactly the recipe the monitor requests:

```
timestamp,actual_TCP_pose,actual_TCP_force,runtime_state
DOUBLE,VECTOR6D,VECTOR6D,UINT32
```

Payload layout, big-endian, 108 bytes, behind the standard 2-byte size + 1-byte type
header:

| Field | Offset | Type |
|---|---|---|
| `timestamp` | 0 | DOUBLE |
| `actual_TCP_pose` | 8 | VECTOR6D |
| `actual_TCP_force` | 56 | VECTOR6D |
| `runtime_state` | 104 | UINT32 |

Protocol version 2 is offered and accepted; version 1 is honored if a client asks for it,
since the monitor falls back to it. Version 2 data packages carry the recipe id byte
ahead of the payload, version 1 does not.

**These constants are duplicated across two languages by necessity.** `test_rtde_server.py`
asserts every offset, the payload size and the recipe string verbatim, so a drift on
either side fails a test instead of producing wrong numbers in a lab CSV.

## 5. Timing, clock and interpolation

- Emitter rate `RTDE_EMU_RATE_HZ = 125`, the CB3 control-loop rate.
- **The stream runs continuously whatever the program state**, as a controller's does:
  packets keep flowing at `STOPPED`, carrying the held last pose and a near-zero force.
  The monitor needs a `STOPPED` packet before `PLAYING` to see the edge that opens a file.
- Translation is linearly interpolated between the 20 Hz trajectory frames. Orientation is
  taken from the nearest frame: the exported trajectory holds orientation constant within a
  cycle, so interpolating it buys nothing and would add a dependency. Documented in the
  module, not assumed silently.
- `timestamp` is monotonic seconds since the server started and **keeps advancing while the
  program is paused or stopped**, exactly as a controller's clock does. A pause therefore
  appears in the CSV as a genuine time gap, which drives the monitor's catch-up path — the
  one that must not emit a burst of back-dated rows on resume. That path currently has a
  unit test against a synthetic stall; this makes it an end-to-end test.
- Velocity for the friction term is differentiated from consecutive interpolated positions
  at the emitter rate.

## 6. `runtime_state` machine

| Viewer event | Emitted sequence |
|---|---|
| Idle, after STOP, after a configuration change | `STOPPED` (1) |
| START | `PLAYING` (2) |
| PAUSE | `PAUSING` (3) for `RTDE_EMU_TRANSITION_PACKETS`, then `PAUSED` (4) |
| RESUME | `RESUMING` (5) for the same window, then `PLAYING` (2) |
| STOP, or end of trajectory | `STOPPING` (0) for the same window, then `STOPPED` (1) |

`RTDE_EMU_TRANSITION_PACKETS = 2` (about 16 ms). Emitting the brief transition states
rather than jumping between the two stable ones is deliberate: it drives the monitor
through the real enum sequence its C suite asserts pair by pair.

Consequence that falls out rather than being special-cased: the configuration radio calls
`set_stop()`, so switching IK branch mid-session closes the current CSV and the next START
opens a new one.

### PAUSE in the viewer

`paused_sim_t` already participates in the clock
(`sim_elapsed = (wall - clock_t0) * SIM_SPEED + paused_sim_t`) and is never set to anything
but zero. PAUSE stores the current `sim_elapsed` into it and clears `running`; RESUME
re-bases `clock_t0` to now and sets `running`. STOP keeps its current hard-stop semantics,
zeroing `paused_sim_t` so the next START replays from frame 0.

## 7. Force model

The signal is derived from the simulator's own geometry, never from a canned waveform:
`surface.py` supplies a per-frame penetration depth that already includes the deliberate
5 mm recontact overshoot of `ARCHITECTURE.md` §5, so the force responds to real trajectory
events.

```
contact:  Fz -> first-order(tau) toward -FORCE_Z_TARGET_N,
               plus a stiffness transient -k * penetration from the depth error
transit:  Fz -> first-order(tau) toward 0
both:     Fx, Fy = -mu * |Fz| * v_hat_xy        (Coulomb friction along TCP travel)
          all three plus Gaussian noise at the FT-300's stated resolution
```

Sign convention follows the monitor plan's own sample row (`ForceZ = -6.012345`): negative
while pressing into the plate.

| Constant | Value | Basis |
|---|---|---|
| `FORCE_MODEL_STIFFNESS_N_PER_M` | 4000.0 | Silicone hemispheric finger; places 6 N at about 1.5 mm penetration |
| `FORCE_MODEL_TAU_S` | 0.05 | `force_mode` regulation rise |
| `FORCE_MODEL_FRICTION_MU` | 0.8 | Silicone on a smooth plate |
| `FORCE_MODEL_NOISE_N` | 0.05 | FT-300 resolution is 0.1 N; sigma chosen for about 0.1 N peak to peak |
| `FORCE_MODEL_SEED` | 20260814 | Fixed, so `--verify-csv` is reproducible |

**These are plausible values, not measurements of this finger and plate.** They are named
and isolated so measured values can replace them later without touching any logic. The
module docstring says so, and so does the emulator's startup banner.

## 8. Provenance and safety

Emulated CSVs land with the same `ACQ_rtde_` prefix and the same header as lab CSVs. For a
research dataset that is a hazard worth designing out:

- The emulator binds `127.0.0.1` only, never `0.0.0.0`. It cannot be reached from the lab
  VLAN and so cannot be mistaken for the robot at `192.168.4.38`.
- The monitor writes `# WARNING: SIMULATED SOURCE - ur5_sim RTDE emulator, not robot data`
  into the header whenever its endpoint is a loopback address.
- Emulator output goes to `datalogger/sim_runs/`, never the repo root.

The emulator sends only RTDE **output** packages. It implements no input path, no register
write and no motion interface, so nothing that speaks to it can be commanded by it.

## 9. CLI surface

| Invocation | Behavior |
|---|---|
| `python -m ur5_sim --visualize` | Serves RTDE on `127.0.0.1:30004` by default. |
| `python -m ur5_sim --visualize --no-rtde-serve` | Visualizer only, no listening socket. |
| `python -m ur5_sim --emulate` | Headless: paces the trajectory in real time and serves RTDE, with no Swift and no matplotlib. Plays once, emits the stop sequence, then exits. |
| `python -m ur5_sim --emulate --runs N` | N consecutive runs separated by `RTDE_EMU_IDLE_S` at `STOPPED`. This is what makes "two runs produce two distinct files" checkable unattended. |
| `python -m ur5_sim --emulate --pause-at T` | Pauses once at simulation time T for `RTDE_EMU_IDLE_S`, then resumes. Makes "a pause does not split the file" checkable unattended, without a human at the button. |
| `python -m ur5_sim --rtde-port N` | Override the port. |
| `python -m ur5_sim --verify-csv [PATH\|auto]` | Check a recorded CSV against the commanded trajectory. |
| `python -m ur5_sim --check` | Unchanged. It has no real-time pacing, so streaming there would compress a three-minute protocol into seconds and produce timestamps that resemble no trial. |

## 10. `--verify-csv`

Comparing CSV row *N* against trajectory time *N* breaks as soon as a pause exists, because
controller time advances while simulation time freezes. The primary check is therefore
geometric and pause-immune.

- **Primary** — distance from each CSV point to the commanded polyline, maximum and RMS.
  The claim is that every recorded point lies on the commanded path. Compared against the
  surface-clamped trajectory, the same array the emulator was handed, not the raw one.
- **Secondary** — row count, effective rate near 50 Hz, `Time` strictly increasing, and
  pause gaps located and reported.
- **Tertiary** — time-aligned pose comparison, run only when no pause gap is found.

Tolerance `1e-5` m. Emitted points are linear interpolations of that same polyline, so the
residual should be formatting noise near `1e-6` m; anything larger is a real frame-chain or
encoding fault. The command exits non-zero on failure so it can gate a scripted run.

## 11. Error handling

The emulator must never take the visualizer down.

| Failure | Behavior |
|---|---|
| Port already in use | Warn, continue without RTDE. The visualizer still runs. |
| No client attached | Accept loop idles; no packet is built. |
| Client disconnects mid-run | Server returns to accepting; the simulation keeps playing. The monitor reconnects on its own 2 s retry. |
| Client too slow to drain | Blocking send with a deadline, **not** a non-blocking send: a non-blocking `sendall` can deliver a partial packet and desync the stream framing permanently, which is worse than the stall it avoids. The stall is confined to the emitter thread and can never reach the render loop, so it costs nothing. A client that misses the deadline is dropped and counted; the monitor reconnects on its own. |
| Viewer closed | Daemon thread plus an explicit `stop()` in a `finally`. |

One client at a time. Real RTDE accepts several; this is a deliberate simplification, and
it is documented as one.

## 12. Testing

Python, stdlib `unittest`, no `gcc` and no `.exe` required, so `unittest discover` stays
green on any machine:

| Module | Covers |
|---|---|
| `tests/test_rtde_server.py` | Framing; encoder round-trip against a decoder written in the test; **the field offsets, payload size and recipe string shared with the C monitor**; handshake including the version 1 fallback; the full `runtime_state` sequence including transition states; interpolation midpoints; client disconnect; port-in-use degradation. |
| `tests/test_force_model.py` | Transit force near zero; contact converging to -6 N within a few time constants; friction opposing travel and vanishing at zero velocity; determinism under the fixed seed. |

C side: one new case in `datalogger/tests/test_rtde_fallback_monitor.c` for the loopback
provenance warning.

End to end, outside `unittest` because it needs the built executable: headless emulator,
monitor, then `--verify-csv`, wired as a `validate.bat` entry.

## 13. `validate.bat`

Options 3 and 4 (visualize) gain a `:start_monitor` helper that checks for
`datalogger\rtde_fallback_monitor.exe`, warns and continues if it is absent, and writes to
`datalogger\sim_runs\`. The monitor starts first and retries until the emulator binds. Two
entries are added: an unattended headless emulator plus monitor run, and verification of
the newest CSV.

## 14. Documentation

- `ARCHITECTURE.md`: a new section for the RTDE emulation contract, kept separate from §7,
  which stays about the design-UI overlay; §2, §9 and §10 tables updated. §10 gains a rule:
  the RTDE wire layout is duplicated in two languages and must stay pinned by the offset
  test.
- `datalogger/README.md`: the local test procedure.
- `README.md` and `CLAUDE.md`: the new commands.

## 15. Out of scope

- Any physics engine. The force model is a named surrogate, not a simulation of contact
  mechanics, and the spec says so wherever the numbers appear.
- RTDE input registers, motion interface, or anything that would let a client command the
  emulator.
- Dashboard Server (port 29999) emulation. The monitor rejected it by design; nothing needs
  it.
- The parked 3-point probe (`ARCHITECTURE.md` §6) stays parked.
- Multiple simultaneous RTDE clients.

## 16. Traceability

| Request | Where it is satisfied |
|---|---|
| A true UR5 emulator: running `ur5_sim` submits data over its port | §3, §4, §5, §9 |
| Protocol | §4 |
| File boundaries | §6, plus the PAUSE control |
| Numeric match | §10 |
| Plausible varying force profile resembling FT-300 data | §7 |
| Check the CSV after any simulation | §10, §13 |
| The launcher starts the monitor with `ur5_sim` | §13 |

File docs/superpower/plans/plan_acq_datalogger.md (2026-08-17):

# Plan — 50 Hz force/pose data logger for UR5 CB3 (on-robot main path)

## Context

Experimental need: record TCP force (Fx,Fy,Fz) and TCP position (X,Y,Z) at 50 Hz during the
ISO/COLIPA spread protocol runs on the UR5 CB3 (RobotIQ FT-300 + 2F-85 passive finger),
20-30 trials of ~3 min each, one uniquely named CSV per trial saved to the robot's USB key.
This plan covers the **main path only**: fully on-controller, no dependency on any
second machine being present, wired, or working.

**Split (2026-08-06)**: this plan was originally combined with a separate fallback
tool (a lab-computer-side monitor reading the robot's RTDE stream). The two are now
independent plans/issues so each can be executed standalone in a fresh session:
- **This plan** — the main path, on-robot only.
- [`plan_rtde_fallback_monitor.md`](plan_rtde_fallback_monitor.md) — the fallback, a
  standalone C executable on a lab computer. Tracked separately (see that plan's own
  issue). Neither plan depends on the other being implemented first; both are required
  deliverables of the overall data-logging effort, executed independently.

The original prompt (kept in section 10) asked for a pure-URScript solution that buffers
11700 samples and writes `/ramdisk/usb/ACQ_log_YYYYMMDD_HHMMSS.csv`. Validation against
the CB3 URScript language shows that as written it is **impossible**; this plan is the
corrected, feasible design that preserves every requirement's intent.

**Output policy (user decision)**: the current, working generation of `etalement.script`
/ `etalement.urp` is **not modified in any way**. The exporter additionally produces a
second pair, `etalement_acq.script` / `etalement_acq.urp`, which is the original program
plus the data-acquisition process. The simulator (`ur5_sim --check/--visualize`) keeps
consuming `etalement.script` only — nothing changes on the sim side.

## 0. Repo state at execution time (checked 2026-08-15, commit 7da2dfb)

- `datalogger/` already exists and holds the **other** path, the RTDE fallback monitor
  (`rtde_fallback_monitor.c`, 909 lines, commit 8c7c30e), its C test harness (147 checks,
  `datalogger/tests/`) and `datalogger/README.md`. **`datalogger/` is exclusively C**
  (operator decision, 2026-08-16): it is the executable that records what the robot
  transmits on its port, and nothing Python belongs there. The acquisition daemon of this
  plan therefore lands in its own folder, **`onrobot/`**, named for the criterion that
  actually separates the two paths - what runs on the controller against what runs on the
  lab computer. Its tests live in `tests/` and ARE collected by `unittest discover`, unlike
  the C harness. `datalogger/README.md` carries a status table whose row "On-robot logger
  (main)" says `Planned` and points at this plan; flipping it to `Implemented`, and writing
  `onrobot/README.md`, is task D1.
- **Robot emulation, two distinct things.** The only emulator that exists as code today is
  `fake_server_thread` in `datalogger/tests/test_rtde_fallback_monitor.c`: it speaks the
  RTDE handshake on `127.0.0.1`, replays a scripted `runtime_state` sequence, and lets the
  monitor's whole socket path run with no robot. It emulates the robot **toward the RTDE
  monitor**, over RTDE, in C, and it is confined to that test binary.
- A second, larger emulator is **specified and planned, not yet implemented**:
  `docs/superpower/specs/spec_rtde_emulator.md` (commit 7c36c13) and
  `docs/superpower/plans/plan_rtde_emulator.md` (2496 lines, 10 tasks, commit 91636ad),
  both on branch **`feat/rtde-emulator`**, both documentation only - no code lands in
  either commit, and `main` is two commits behind them. It turns `ur5_sim` itself into the
  robot: `ur5_sim/rtde_server.py` (big-endian RTDE encoder, TCP server on
  `127.0.0.1:30004`, 125 Hz emitter thread, `runtime_state` machine, interpolation from
  the trajectory's native 20 Hz up to the controller rate; stdlib only, no matplotlib and
  no Swift, so it tests headless), `ur5_sim/force_model.py` (FT-300 surrogate: contact
  stiffness, regulation transient, Coulomb friction, seeded noise; pure, no I/O),
  `RTDE_EMU_*` / `FORCE_MODEL_*` constants in `ur5_sim/config.py`, a real PAUSE in the
  viewer, `--emulate` / `--rtde-serve` / `--verify-csv` in `ur5_sim/cli.py`, and a
  loopback-provenance line added to the monitor's CSV header. Intended invocation:
  `python -m ur5_sim --emulate --runs 2 --pause-at 30`. Its client is the **already
  implemented** C monitor, which is what makes it verifiable end to end.
- **Consequence for the acquisition path.** That emulator speaks RTDE (port 30004, robot
  toward a passive listener) and validates the **fallback** path; the acquisition path
  needs the opposite shape, a client that pushes samples into the daemon on 50100 and a
  server that streams FT-300 text frames on 63351. There is no direct substitution, and
  neither plan blocks the other. Two seams cross over once `feat/rtde-emulator` is
  implemented and merged:
  - `ur5_sim/force_model.py` replaces the placeholder force source of the fake FT-300
    server in E1 (one call site, `_force_at(t)`), so both paths are then exercised with
    the same contact model instead of two unrelated invented ones.
  - `--verify-csv` carries over **with one small tolerance**, not unchanged: its primary
    check is geometric (distance from each recorded point to the commanded polyline,
    max and RMS, tolerance 1e-5 m) and therefore metadata-agnostic, and §5 gives both
    paths the same seven data columns. What differs is the metadata block (`# Data
    Source: RTDE fallback monitor` against the acq block of §5) and the meaning of
    `Time` (RTDE controller timestamp against robot tick time from the URScript thread).
    A reader that skips `#` lines and does not assume the RTDE provenance line covers
    both. That is the cheapest cross-validation available between the on-robot logger and
    the RTDE monitor.
  E1 is therefore written **standalone and small**, with no import of the unimplemented
  modules and those two seams named in its docstring. Direction of dependency is one way
  and must stay so: `acq_emulator.py` is dev-machine only and may import `ur5_sim`;
  `acq_logger_daemon.py` runs on the controller and may import **nothing** but the
  standard library.
- **Branch and merge order.** This plan is executed on its own branch off `main`. It shares
  no code file with `feat/rtde-emulator`; the only overlap is documentation
  (`datalogger/README.md`, `ARCHITECTURE.md`, `CLAUDE.md`, `validate.bat`), so a conflict
  at merge time is textual, never behavioral. Whichever branch merges second rewrites its
  own rows in the `datalogger/README.md` status table.
- Nothing else is touched: `etalement.script`, `etalement.urp`, the `design/` generation
  path and `ur5_sim/` behavior stay byte-identical (guarantee 1 of §3).
- **Defects found outside this scope are not repaired here.** Auditing the code this plan
  builds on turned up seven, from an unvalidated settings-load path that can export a 200 N
  force target to a hand-edit guard that fails open. They are registered with severities,
  fixes and candidate tests in
  [`erreur_hors_datalogger.md`](erreur_hors_datalogger.md). Two of them touch code this
  plan reuses (`_validate_script_memory` in F2, `check_overwrite` in F3) but change no
  behavior it depends on, so the two efforts stay independent; a diff that both added the
  acquisition feature and repaired unrelated code could not be reviewed on either count.

## 0-bis. Execution model - Opus here, Sonnet subagent for the mechanical work

The plan is executed inside one chat session. Opus keeps the design, the URScript emission
and every verification; a Sonnet subagent takes the mechanical code and **all** test files.

Rules of the split:

- **Never delegated**: acceptance of a returned diff, the byte-identity check on
  `etalement.script`, the pose-equivalence review, the final suite run, `pip-audit`, and
  the decision that a task is done. Counter-validation stays in this session, on Opus.
- **One subagent per task**, `subagent_type: general-purpose`, `model: sonnet`, run in
  background when the task has no open dependency. A subagent starts cold: its prompt
  carries the full contract (files to touch, invariants, exact acceptance command), never
  a pointer such as "see the plan".
- Opus reviews the diff of each task before dispatching the next wave.

**Constraint checklist that every Sonnet prompt must repeat verbatim:**

1. Tests use stdlib `unittest`; **pytest is not installed** in `.venv`.
2. `acq_logger_daemon.py` must stay valid under **Python 2.7** (controller) and run under
   the venv's Python 3.13 (tests): no f-strings, `print()` as a function, no `pathlib`, no
   type hints in that one file. Files are written in **binary mode** with explicit `\n`,
   so a test on Windows sees the same bytes the controller writes.
3. Settings invariant (ARCHITECTURE.md §8): never `from design.params import X` for a
   value the operator can edit. The `ACQ_*` constants are export-time constants kept out
   of `design/settings_spec.SPECS`, so `params.ACQ_LOG_PORT` module-attribute access is
   allowed; if one is ever exposed in the settings window it must move to
   `get_settings()`.
4. `etalement.urp` is **hand-edited by the operator** between robot trials. Neither
   `generate_urp()` nor any new code may write it. `etalement_acq.urp` goes through the
   existing `check_overwrite()` digest guard, like every other export.
5. CB3 rules (ARCHITECTURE.md §4): no `stopl`/`movel` inside a thread, no list slicing,
   memory budget asserted with `_validate_script_memory()`.

**Task table.** Complexity is stated for the code, not the prose.

| # | Task | Complexity | Owner | Depends on |
|---|---|---|---|---|
| A1 | `onrobot/acq_logger_daemon.py` against the contract in §3-bis | Medium (stdlib sockets, threads, CSV bytes) | Sonnet | §3-bis (Opus) |
| A2 | `onrobot/urmagic_acqlogger.sh` | Low | Sonnet | - |
| B1 | `design/params.py`: `ACQ_*` constants and acq output paths | Low | Sonnet | - |
| E1 | `onrobot/acq_emulator.py` (fake FT-300 server + fake robot client replaying real poses), standalone, with the two `feat/rtde-emulator` seams named in the docstring | Medium | Sonnet | §3-ter (Opus) |
| C1 | `_build_acq_lines()`: logger thread, tick alternation, anchor insertion, STOP handshake | **High** (CB3 semantics, 8 ms tick, thread rules, anchor stability) | **Opus** | B1 |
| C2 | `generate_urscript_acq()` / `generate_urp_acq()` + `design/app.py` wiring + overwrite guard | Medium | Sonnet | C1 |
| T1 | `tests/test_acq_logger_daemon.py` | Medium | Sonnet | A1, E1 |
| T2 | `tests/test_acq_export.py` (the 3 guarantees of §3) | Medium | Sonnet | C1, C2 |
| D1 | `onrobot/README.md`: acq section, deployment steps, status row flipped | Low | Sonnet | A1, A2, C2 |
| D2 | `ARCHITECTURE.md` + root `CLAUDE.md`: acq entries and invariants | Medium (states invariants) | **Opus** | C1, C2 |
| V1 | Full suite, byte-identity of `etalement.script`, `ur5_sim --check`, `pip-audit` | Verification | **Opus, never delegated** | all |

Waves: (1) A1 + A2 + B1 in parallel; Opus drafts C1 meanwhile. (2) E1 + C1 finalized.
(3) C2, then T1 + T2 in parallel. (4) D1 + D2. (5) V1.

## 0-ter. Questions to ask the user at execution start (blocking, per prompt requirement)

1. **Exact PolyScope version** — ANSWERED: **PolyScope 3.11.0.82155 (20 August 2019)**,
   CB3 controller. Confirmed facts for this exact build (all hold for the 3.x branch):
   8 ms thread tick, `socket_send_line` available (list arg auto-serialized), no file
   I/O API, no date/time builtin, no `list_append`, no list slicing. Nothing in this
   plan needs revisiting for a newer/older CB3 build; only an e-Series controller
   (5.x, 2 ms tick) would change §4.
2. **Confirm the urmagic daemon approach is acceptable** (a `urmagic_*.sh` on the USB key
   runs as root on insertion — standard UR mechanism, script fully auditable, stdlib-only
   Python). If the user has SSH access to the controller instead, install the daemon that
   way and skip the magic file.
3. **FT-300 URCap installed and streaming?** — ANSWERED: **URCap 1.11.0.29 (2017)**.
   Researched facts (Robotiq FT Sensor Instruction Manual, DoF forum, see citations
   below): port 63351 is a **fixed** controller-side TCP socket opened once the FT
   Sensor URCap is active; it is not a configurable field anywhere in PolyScope. In
   PolyScope: **Program Robot -> Installation tab -> FT Sensor** (left pane) opens the
   sensor dashboard (RS-485 wiring status, Calibration tab with a zeroing wizard); no
   port number ever appears in that UI, by design. Data-stream mode is started at the
   sensor register level (write `0x0200` to Modbus register 410) and the URCap keeps
   it running once installed; the daemon in this plan just connects to
   `127.0.0.1:63351` and reads whatever is already streaming (see §3/daemon FT-300
   reader). Minimum PolyScope for the URCap is 3.5 -- our 3.11.0.82155 (2019) qualifies,
   and the sensor manual line predates and covers the 2017 URCap release. Deployment
   risk kept in the plan (§8): the exact wire format (field order/separator) is not
   confirmed from public docs for this URCap build, so `test_acq_logger_daemon.py`
   must exercise the parser against the documented Robotiq format and the daemon
   should log a raw sample once at connect time for the first on-robot smoke test, so a
   format mismatch is caught before the file-safety net removes it and NOT silently
   miscolumned into the CSV.
   Sources: [Robotiq FT Sensor Instruction Manual](https://assets.robotiq.com/website-assets/support_documents/document/FT_Sensor_Instruction_Manual_PDF_20181218.pdf),
   [FT Sensor Installation (PolyScope tab path, min. version 3.5)](https://assets.robotiq.com/website-assets/support_documents/document/online/FT_Sensor_Instruction_Manual_Web_20181218.zip/FT_Sensor_Instruction_Manual_Web/Content/In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),
   [Export Data from FT 300 and FT 150 (port 63351, DoF forum)](https://dof.robotiq.com/discussion/494/export-data-from-ft-300-and-ft-150).

## 1. Validation of the original prompt — issues found (CB3 / PolyScope 3.x facts)

| # | Prompt requirement | CB3 reality | Resolution |
|---|---|---|---|
| 1 | Write CSV to `/ramdisk/usb/` from URScript | URScript has **no file API at all** (motion, math, sockets, textmsg only — deliberate sandbox) | On-controller Python daemon writes the file; URScript talks to it over loopback socket |
| 2 | Filename from controller date/time in URScript | **No date/time function** in URScript 3.x | Daemon uses the controller's Linux clock (`datetime`) for `ACQ_log_YYYYMMDD_HHMMSS.csv` |
| 3 | Preallocate 11700-sample arrays, "no list_append" | `list_append` **does not exist** on CB3 anyway; lists are fixed-size literals, nested lists (`force_log[i] = [Fx,Fy,Fz]`) unsupported, practical list sizes are hundreds not thousands, and an 11700-element literal blows the PolyScope program memory budget | Buffer lives in the daemon's RAM (unlimited). URScript stays allocation-free: one reusable 7-element list per sample |
| 4 | Exact 20 ms sampling via timing control | Thread `sync()` tick is 8 ms on CB3 → 20 ms is 2.5 ticks, not reachable exactly | Alternate 2-tick/3-tick periods (16/24 ms, mean exactly 20 ms, jitter ±4 ms); every sample carries its true tick-time stamp, so analysis is exact |
| 5 | Timestamp = "actual acquisition timestamp" | No wall clock in URScript | Column 1 = robot tick time (s, from the 8 ms sync counter, authoritative relative time). Daemon adds a second column with controller wall-clock arrival time (absolute, ±ms) |
| 6 | `get_tcp_force()` as force source | Built-in is a joint-current **estimate** (multi-newton error) while a calibrated FT-300 streams on local port 63351 at 100 Hz | Primary: daemon reads FT-300 stream and merges latest force into each sample (user-approved). Fallback flag: URScript sends `get_tcp_force()` values instead |
| 7 | String CSV rows built in URScript | CB3 3.x lacks `to_str`/`str_cat` (version-dependent) | `socket_send_line(buf)` with a list auto-serializes (`[t,x,y,z,...]`) on CB3 — no string building at all |
| 8 | "No blocking ops in acquisition loop" | `socket_send` can block only if the peer stalls | Peer is a loopback daemon that drains continuously; 64 KB TCP buffer absorbs any hiccup; send is ~50 µs |
| 9 | No `stopl`/`movel` in threads, no `[0:3]` slicing (project CB3 rules) | Respected: logger thread only reads pose + sends; no slicing anywhere | — |

Conclusion: intent of every requirement is preserved; only the **locus of the buffer and
of the file write moves from URScript (impossible) to a daemon on the same controller**.

## 2. Architecture (2 components, both on the robot / USB key)

```
USB key
 ├─ urmagic_acqlogger.sh      -> runs on insertion, launches daemon (nohup, python2)
 ├─ acq_logger_daemon.py      -> loopback TCP server 127.0.0.1:50100
 └─ ACQ_log_*.csv               <- written here at end of each trial

URScript (data_logger thread, 50 Hz)
   --[loopback socket, one list per sample]--> daemon RAM buffer
                                               + FT-300 reader (127.0.0.1:63351, keeps latest Fx,Fy,Fz)
   --"STOP" sentinel at end of motion------->  daemon writes metadata + CSV to USB, replies "OK <filename>"
```

- During motion: **zero USB I/O** (daemon buffers in RAM only).
- After motion: daemon writes the whole file in one pass, fsync, close, reply.
- Repeat trials: each program run opens a new session -> new timestamped file; daemon adds
  `_1`, `_2` suffix on the (unlikely) same-second collision. No overwrite possible.

## 3. Deliverables (new files in the existing `datalogger/` folder + additive changes in `design/`)

| File | Content |
|---|---|
| `onrobot/acq_logger_daemon.py` | Full contract in **§3-bis**. Python **2.7-compatible**, stdlib only (CB3 ships Python 2.7). Threads: (a) FT-300 reader — connects 63351, parses `(Fx, Fy, Fz, Mx, My, Mz)` text stream, keeps latest triple, auto-reconnect; (b) log server on 50100 — accepts URScript connection, parses `[t,x,y,z]` (or 7-field fallback) lines, appends to in-RAM list, on `STOP` writes CSV (metadata block + header + rows) to detected USB mount, replies status. USB mount auto-detected from `/proc/mounts` (vfat/exfat under `/media` or `/programs`); falls back to `/tmp` with a warning if no USB. |
| `onrobot/urmagic_acqlogger.sh` | Kills previous instance, launches daemon with `nohup`, logs to USB. Short, auditable. |
| `onrobot/acq_emulator.py` | Dev-machine only. Fake FT-300 server on 63351 plus a fake robot client that replays the real poses of `etalement.script` into port 50100 at 50 Hz and closes with `STOP`. Full contract in §3-ter. Makes the offline verification an end-to-end run instead of a unit test, and is the acquisition-side mirror of the C `fake_server_thread`. |
| `design/params.py` (additions only) | New constants per ARCHITECTURE rule 1: `ACQ_LOG_PORT = 50100`, `ACQ_SAMPLE_TARGET_MS = 20`, `ACQ_MAX_SAMPLES = 11700`, `ACQ_SCRIPT_PATH` / `ACQ_URP_PATH` (`etalement_acq.script` / `.urp`). No existing constant touched. |
| `design/export.py` (additions only) | New `_build_acq_lines(base_lines)` wraps the untouched output of `_build_urscript_lines()`: inserts (a) header comment block for the acquisition process, (b) BeforeStart socket-open + abort-popup if daemon absent, (c) `thread data_logger():` definition, (d) `run data_logger()` right after `set_tcp(...)`, (e) shutdown + STOP handshake after the final retreat, before program end. Insertion via stable anchor lines already emitted by the builder (e.g. the `set_tcp` line and the retreat comment block); a missing anchor is a hard export error, not a silent skip. New `generate_urscript_acq()` / `generate_urp_acq()` reuse `_validate_script_memory()` on the acq files. `generate_urscript()` / `generate_urp()` are **not modified**. |
| `design/app.py` (additions only) | `--export` / `--export-urp` now also write the `_acq` twin after the original (original files written first, byte-identical to today). |
| `onrobot/README.md` | Deployment procedure (USB insertion, daemon check, load `etalement_acq.script`, run, retrieve CSV), version-dependency notes, FT-300 vs `get_tcp_force()` switch, and the rule: simulation always uses `etalement.script`. |
| `tests/test_acq_logger_daemon.py` | stdlib `unittest`, offline: fake FT-300 server + fake URScript client on loopback; asserts CSV metadata block, header `Time,ForceX,ForceY,ForceZ,PoseX,PoseY,PoseZ`, row count == sent count, no trailing preallocated rows, filename format, collision suffix, STOP handshake, buffer cap at 11700 with clean auto-stop. Must run on Windows dev machine (pure sockets, temp dir as fake USB). Daemon code stays Python-2.7-valid but the test may run it under the project venv's Python 3 — write it 2/3-compatible (no f-strings, `print()` function, etc.). |
| `tests/test_acq_export.py` | Three guarantees: (1) **regression** — lines produced for `etalement.script` are identical with and without the acq feature present (original untouched); (2) **equivalence** — `parse_poses(etalement_acq.script)` returns exactly the same 4-tuples as `parse_poses(etalement.script)` (lenient parser ignores the thread block; motion unchanged); (3) **content** — acq script contains the thread def, `keep_logging`, bounds guard `log_index < ACQ_MAX_SAMPLES`, socket open before motion, STOP after retreat, and no `movel`/`stopl`/slicing inside the thread block. Memory budget asserted on the acq file too. |

## 3-bis. Daemon contract (authored by Opus, implemented by Sonnet in task A1)

`onrobot/acq_logger_daemon.py`, stdlib only, valid Python 2.7 and 3.x. Tests load it by
path (`importlib.util.spec_from_file_location`), so it stays a **plain module**: no package
`__init__.py`, no relative import, no assumption about its parent folder. That is what lets
the same file be copied alone onto the USB key.

Module constants: `DEFAULT_LOG_PORT = 50100`, `DEFAULT_FT_PORT = 63351`,
`MAX_SAMPLES = 11700`, `HEADER = "Time,ForceX,ForceY,ForceZ,PoseX,PoseY,PoseZ"`.

Pure functions (no socket, no clock, no disk - these carry most of the test surface):

- `parse_ft_line(line)` -> `(fx, fy, fz)` or `None`. Accepts the documented Robotiq form
  `( 0.12 , -3.40 , 5.60 , 0.00 , 0.00 , 0.00 )`: parentheses optional, whitespace
  irrelevant, comma separated, 6 fields; a 3-field variant is also accepted. Anything else
  returns `None` (never raises).
- `parse_sample_line(line)` -> `(t, x, y, z)` or `(t, x, y, z, fx, fy, fz)` or `None`.
  Accepts what `socket_send_line` emits for a list on CB3, `[0.016,0.412,-0.298,0.101]`,
  with or without brackets.
- `find_usb_mount(proc_mounts_text)` -> path string or `None`. Pure function over the text
  of `/proc/mounts`; keeps `vfat`/`exfat` mounts under `/media` or `/programs`. The caller
  falls back to `/tmp` and records that fallback in the metadata block.
- `format_csv(meta, rows)` -> **bytes**. `%.3f` for `Time`, `%.6f` for the other six
  columns, `\n` line ending, ASCII. The file is opened `'wb'`, written, `flush()`,
  `os.fsync(f.fileno())`, closed - in that order.
- `next_free_name(dir_listing, stem)` -> filename. `ACQ_log_YYYYMMDD_HHMMSS.csv`, and on
  collision `_1`, `_2`, and so on. Overwriting is impossible by construction.

Stateful classes (constructor takes its dependencies, so tests need no USB, no wall clock
and no real sensor):

- `FTReader(host, port)`: `.start()`, `.stop()`, `.latest()` -> last `(fx, fy, fz)` or
  `(0.0, 0.0, 0.0)` before the first frame, `.ok` False until one frame parses. Reconnects
  with a 1 s backoff and logs only on state change. Prints one **raw** sample at first
  connect (this is the mitigation for the wire-format risk of §8: a mismatch must be seen
  in the log before it is silently miscolumned into a CSV).
- `LogServer(port, ft_reader, out_dir_resolver, clock)`: `.serve_one_session()` accepts one
  connection, reads lines until `STOP <n>` or EOF, and returns
  `SessionResult(path, n_rows, n_bad, ft_ok, truncated)`.

Protocol on port 50100, line oriented, ASCII:

| Received | Daemon action | Reply |
|---|---|---|
| a sample line | append to the RAM list | none |
| an unparsable line | increment `n_bad`, keep going | none |
| a sample line whose first field is **negative** | read the second field as the robot's own sample count, do not append | none |
| `STOP <n>`, or a bare `STOP` | write the CSV, fsync, close | `OK <filename> <rows>\n` |
| `STOP <n>` on a write failure | keep the RAM buffer intact | `ERR <reason>\n` |
| `RETRY` | rewrite from the retained buffer | `OK ...` or `ERR ...` |

**Amendment, 2026-08-15 (C1).** The plan originally had the robot send `STOP <log_index>`.
That string cannot be built on CB3: PolyScope 3.x has neither `to_str` nor `str_cat`, so
`"STOP " + acq_index` has no valid form (this is issue 7 of §1, whose consequence for the
handshake was missed when §4.5 was written). The emitted script therefore sends the count as
a **sentinel list with a negative first field**, `[-1.0, acq_index, 0.0, 0.0]`, immediately
followed by the literal `"STOP"`, which is a constant and legal. The daemon accepts both
that pair and the plain textual `STOP <n>`, which is what the emulator and the tests use.
A count that disagrees with the number of rows received is reported, not corrected: it is
the only evidence available that lines were dropped.

At `MAX_SAMPLES` the server stops appending, **keeps draining** the socket so the robot
never blocks on a full TCP buffer, and sets `truncated` in the metadata. All stdout lines
are prefixed `[ACQ]`; `urmagic_acqlogger.sh` redirects them to a log file on the USB key.

## 3-ter. Emulator contract (authored by Opus, implemented by Sonnet in task E1)

`onrobot/acq_emulator.py`, Python 3, dev machine only, never shipped to the robot. It is
the acquisition-side mirror of the C `fake_server_thread`, and it is what makes the offline
smoke run of §7 a real end-to-end exercise rather than a unit test.

- `--ft` runs the fake FT-300: TCP server on 63351, one text frame per 10 ms in the
  Robotiq format. Force source is a placeholder (constant plus sine plus seeded noise)
  whose call site is one function, `_force_at(t)`, so `ur5_sim/force_model.py` replaces it
  in one line once `feat/rtde-emulator` is implemented and merged. Seeded, like that
  module, so a produced CSV is reproducible.
- `--robot etalement.script` parses the real program with `ur5_sim.parsing.parse_poses`,
  then plays the poses into the log port at 50 Hz with the alternating 16/24 ms tick times
  of §4.3, and finishes with `STOP <n>`. Exits non-zero unless the reply starts with `OK`.
- `--samples N`, `--rate`, `--port`, `--ft-port` to drive the edge cases (buffer cap,
  daemon absent, FT-300 absent).
- The `in_contact` flag returned by `parse_poses` selects contact force vs near-zero force,
  so the produced CSV can be eyeballed against the 6 N target the same way a real trial is.

## 4. Acquisition block design (emitted into `etalement_acq.script` by `_build_acq_lines`)

Structure (CB3-safe, fully commented per prompt's code-quality section). The motion is
the real, unchanged 6-cycle spread program — no placeholder needed:

1. **Config block**: `LOG_PORT=50100`, `SAMPLE_MS=20`, `MAX_SAMPLES=11700` (daemon enforces
   too), `USE_INTERNAL_FORCE=False` (fallback switch).
2. **Globals**: `keep_logging = True`, `log_index = 0`, `t_ticks = 0`, one reusable
   `sample_buf` list. All created before motion. No allocation in the loop.
3. **`thread data_logger():`**
   - open socket to `127.0.0.1:LOG_PORT` (opened before motion starts, in BeforeStart
     region, so a missing daemon aborts the run with a popup before the robot moves).
   - loop while `keep_logging` and `log_index < MAX_SAMPLES`:
     - alternate `sync()` x2 / x3 (16/24 ms -> mean 20.000 ms); `t_ticks` += ticks.
     - `p = get_actual_tcp_pose()`; fill `sample_buf` indices: `t_ticks*0.008`, `p[0]`,
       `p[1]`, `p[2]` (+ `get_tcp_force()[0..2]` only if fallback switch on).
     - `socket_send_line(sample_buf, ...)` — list auto-serialized, no strings built.
     - `log_index = log_index + 1`.
   - loop exit on either condition == automatic stop at buffer cap. No motion commands,
     no slicing, no stopl/movel in thread (project rule, section 4 of ARCHITECTURE.md).
4. **Main program**: original lines from `_build_urscript_lines()` verbatim; acq inserts
   `lt = run data_logger()` right after `set_tcp(...)` and, after the final retreat,
   shutdown: `keep_logging = False`, `sleep(0.1)`, `kill lt`, confirm `log_index` frozen.
5. **Export handshake**: send `STOP <log_index>` line; `socket_read_string` the daemon
   reply with timeout; `popup` shows `OK ACQ_log_....csv (N samples)` or the daemon's
   error text (file open failed, no USB, ...). Data stays in daemon RAM on failure, and
   a `RETRY` line can be sent from a re-run popup path.
6. **Version-dependency notes block** (prompt item 15): confirmed against PolyScope
   3.11.0.82155 (CB3, Aug 2019) — 8 ms tick vs 2 ms on e-Series; `socket_send_line` list
   serialization available; no file/date APIs on this build; FT-300 port dependence on
   the Robotiq URCap version installed.

## 5. CSV format (written by daemon)

```
# Robot Model: UR5 CB3
# PolyScope Version: 3.11.0.82155 (20 August 2019)
# File Creation Date: YYYY-MM-DD
# File Creation Time: HH:MM:SS
# Target Acquisition Frequency: 50 Hz
# Maximum Buffer Size: 11700
# Actual Number of Collected Samples: N
Time,ForceX,ForceY,ForceZ,PoseX,PoseY,PoseZ
0.000,-0.123456,0.234567,-6.012345,0.412345,-0.298765,0.101234
...
```

- `Time` = robot tick time (s, 3 decimals — 8 ms resolution). Optional extra column
  `HostTime` (daemon arrival clock) can be added; decide at execution (keeps header
  exactly as specified by default).
- Floats: 6 decimals (m and N — engineering precision).
- Only `N = log_index` rows written; the RAM buffer is a Python list appended per received
  line, so "unused preallocated entries" cannot exist by construction.
- This exact 7-column header (`Time,ForceX,ForceY,ForceZ,PoseX,PoseY,PoseZ`) is also
  used by the independent fallback tool in `plan_rtde_fallback_monitor.md`, with a
  different filename prefix (`ACQ_rtde_` vs `ACQ_log_`) so the two outputs are never
  mistaken for each other even if both land in the same folder.
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

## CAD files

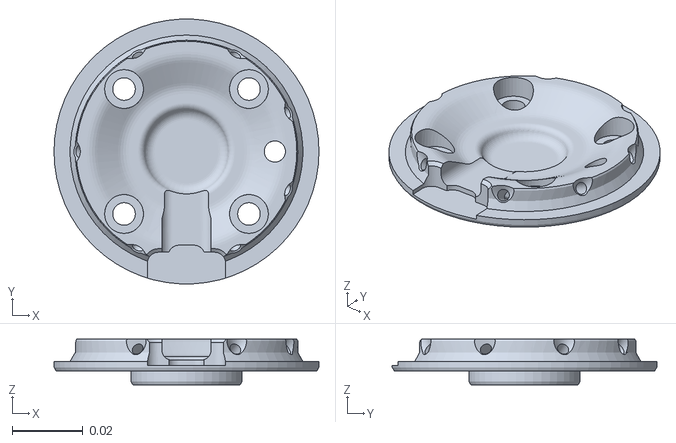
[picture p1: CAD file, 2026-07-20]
meshes/robotiq/robotiq_ft300-G-062-COUPLING_G-50-4M6-1D6_20181119.STL
0.075 x 0.0749 x 0.013

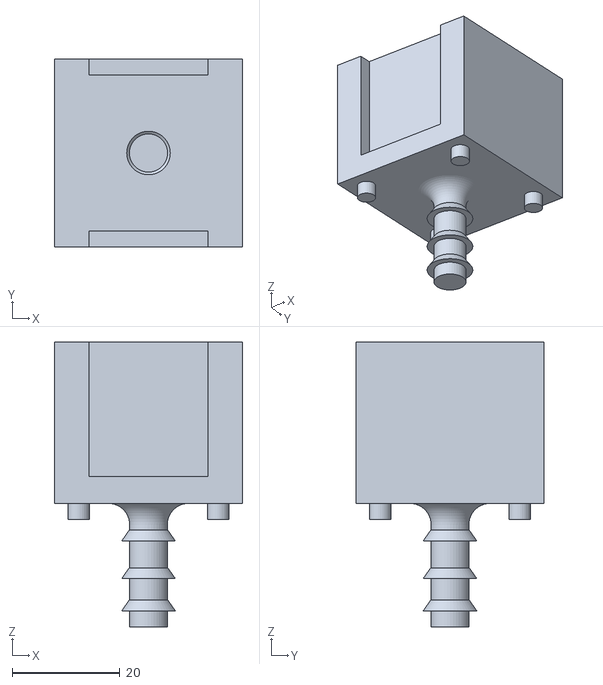
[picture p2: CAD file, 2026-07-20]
meshes/Support doigt.stl
35.0 x 35.0 x 53.0

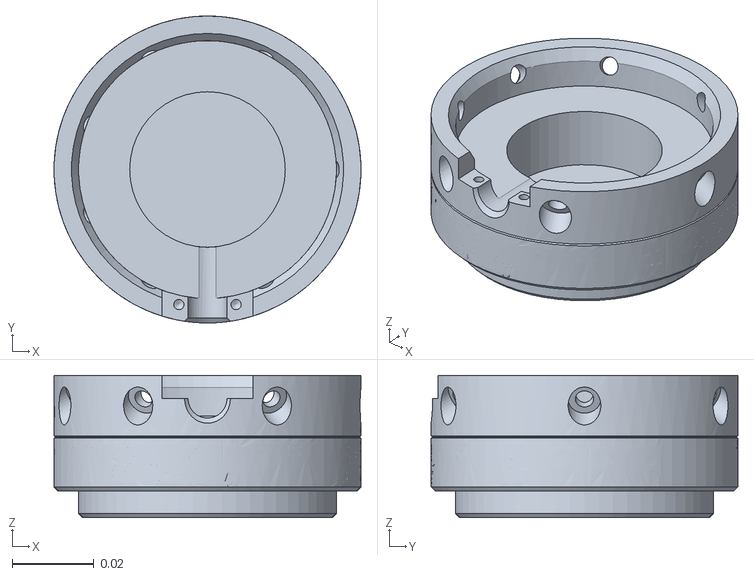
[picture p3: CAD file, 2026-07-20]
meshes/robotiq/robotiq_ft300.STL
0.075 x 0.075 x 0.0348

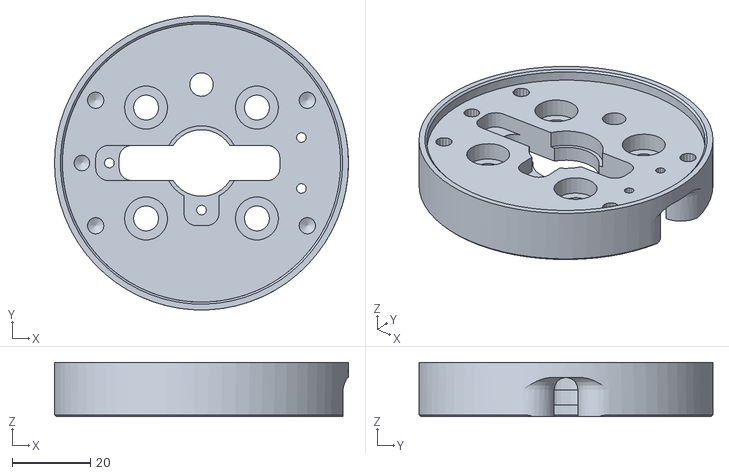
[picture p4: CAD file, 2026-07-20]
meshes/robotiq/robotiq_gripper_coupling.stl
75.0 x 74.9 x 13.9

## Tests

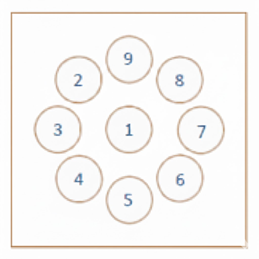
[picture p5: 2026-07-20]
meshes/TestMeasure.png

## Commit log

2026-07-20 Initial commit: UR5-Script-Design (renamed from UR5Script)
    Design UI + offline simulator/validator for the ISO/COLIPA cosmetic-spread
    protocol on UR5 CB3 + RobotIQ FT-300 + 2F-85.
    [Support doigt.stl, robotiq_arg2f.xacro, robotiq_arg2f_85_model_macro.xacro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]
2026-07-20 Add README: project overview, export options, dependencies, run instructions
    Documents the current etalement.script/.urp export and the planned additive
    etalement_acq.script/.urp data-acquisition option (issue #1), and points to
    ARCHITECTURE.md for the full design.
2026-08-05 Relocate plans to docs/superpower/plans/, add specs folder convention
    Moves plan_variables_UI.md and plan_optimisation_urscript.md from repo
    root, adds the acquisition-logger plan (student name scrubbed from
    internal filenames too: acq_logger_daemon.py / urmagic_acqlogger.sh /
    test_acq_logger_daemon.py, not just the CSV prefix caught earlier).
    Documents the docs/superpower/plans + docs/superpower/specs convention
    in CLAUDE.md. Updates README's issue link (old #1/#2 deleted for the
    same privacy reason, current is #6).
2026-08-05 Add lab network topology to acquisition-logger plan
    IE5000 switch, robot on port 8/VLAN 4, static IP 192.168.4.25 (mask
    reported as /38, flagged as invalid/likely typo pending confirmation),
    no DHCP/no Internet on VLAN 4. Port 4 free on same VLAN for a wired
    laptop. Wi-Fi laimi-robot noted as unreliable, not recommended.
    FT-300 streaming on this path not yet verified, user testing 2026-08-06.
2026-08-06 Switch RTDE fallback monitor from PowerShell to C (static exe)
    Lab computer confirmed Windows with cmd but uncertain PowerShell
    version/availability. A statically-linked C executable (MinGW-w64 gcc,
    already installed on the dev machine) has no runtime dependency beyond
    cmd.exe and ws2_32.dll, both universal on any Windows install -- more
    robust than betting on PowerShell 5.1 being present, and needs no new
    toolchain to build. Winsock2 sockets, hand-rolled big-endian decode
    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
2026-08-10 Confirm lab computer specs: Windows 10 Pro 64-bit, i7-6700, 16GB RAM
    Resolves the earlier "PowerShell uncertain" note to "present" (Windows
    10 ships 5.1), but the C/static-exe decision stands unchanged -- it
    was already justified independent of PowerShell availability. Pins the
    build target to x86_64-w64-mingw32 (matches confirmed 64-bit OS,
    already gcc's default here). Notes hardware is well above what this
    tool needs, no performance/memory risk.
2026-08-15 Add spec for the ur5_sim RTDE emulator
    Design specification for making ur5_sim serve a UR5 CB3 RTDE stream on
    loopback, so the already-built rtde_fallback_monitor.exe can be exercised end
    to end with no robot present. First spec in docs/superpower/specs/.
    Three constraints found while designing it, each recorded in the spec:
    - The existing UDP telemetry channel cannot serve the monitor. Different
    transport, different encoding, and the monitor refuses to log until a recipe
    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
2026-08-15 Add the implementation plan for the ur5_sim RTDE emulator
    Ten TDD tasks implementing docs/superpower/specs/spec_rtde_emulator.md, each
    ending in an independently testable deliverable and a commit.
    Self-review of the plan against the spec corrected one design error before it
    could be built: the spec called for a non-blocking send that drops a packet
    when the client is slow. A non-blocking sendall can deliver a partial packet
    and desync the stream framing permanently, which is worse than the stall it
    avoids, and the stall is confined to the emitter thread where it can never
    reach the render loop. Both documents now specify a blocking send with a
    deadline, dropping the client rather than the f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
2026-08-15 Add a runtime settings layer and its operator UI
    The protocol constants lived in design/params.py and were imported by
    value, so `from design.params import X` bound the number at import time.
    Changing a value in memory had no effect on the exported script, which is
    why the design UI could only offer the five path-shape sliders and why
    everything else had to be edited in the source and re-exported.
    Introduce design/settings.py, a dataclass read at call time, with its
    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
2026-08-15 Assign a model to every task in the RTDE emulator plan
    Seven of the ten tasks create new standalone modules whose code and tests the
    plan already carries in full, so they are transcription plus verification and
    run on Sonnet. Three edit existing files or carry a correctness trap and stay
    on Opus: the TCP server and its thread (partial-send desync, SO_REUSEADDR
    meaning the opposite of the usual on Windows), the viewer PAUSE control, and
    the CLI plus viewer wiring.
    Task 7's Model line now also records a plan defect rather than hiding it: the
    buffer names in its snippets were written without checking viewer.py and cli.py,
    so an implementer transcribing them literally would fail. The line says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
2026-08-15 Log two out-of-scope defects and a concurrent-writing protocol
    Adds F8 and F9 to the out-of-scope register, plus the rule that sends future
    findings there, in plan_rtde_emulator.md.
    F8: the monitor's CSV writes "# Data Source: RTDE fallback monitor
    (192.168.4.14)" as a string constant, so every file claims the lab computer
    whatever machine recorded it, while the neighbouring endpoint line is derived
    from argv and can contradict it. The C test asserts the literal, which makes
    the wrong value the specified behavior and would make a correction look like a
    regression. Proposed fix derives the host from gethostname() and the address
    from getsockname() on the live socket, which is also the only w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
2026-08-15 Add the acquisition-logger constants to design/params.py
    Six additive constants for the on-robot data logger: the loopback port the
    daemon listens on, the fixed Robotiq FT Sensor URCap port, the 20 ms target
    period, the 11700-sample cap, and the two acq output paths. Nothing existing
    is touched and none of them enters settings_spec.SPECS, so the settings
    fingerprint and the exported header block are unchanged.
    Verified: tests.test_settings and tests.test_settings_persistence green (34
    tests), and a headless export still matches tests/fixtures/golden_headless.script
    byte for byte.
2026-08-15 Pin the export verification to the golden fixture, log F10
    The acquisition plan's V1 step compared a regenerated export against the
    committed etalement.script. That reference is wrong: a headless export
    reproduces tests/fixtures/golden_headless.script byte for byte (61366
    characters, 502 lines), while the committed artifact is a different one
    (817 lines, 113131 bytes) produced from the interactive UI. Verification now
    targets the fixture.
    The underlying problem, that the committed script is reproducible by no
    documented command and records nothing about the configuration that produced
    it, is logged as F10 in erreur_hors_datalogger.md with its candidate tests.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
2026-08-15 Emit the 50 Hz acquisition block into an acq twin of the script
    _build_acq_lines() wraps the untouched output of _build_urscript_lines() by
    inserting at three anchors: the logger thread before def etalement(), the
    socket open and thread start right after set_tcp(), and the stop handshake
    after the final retreat. No existing line is modified or removed, so the
    motion is provably identical; a missing anchor raises rather than silently
    emitting a program without its logger.
    CB3 constraints held: no movel/stopl inside the thread, no list slicing, no
    allocation in the loop (one reusable indexed list), and no string built at
    runtime. The sample count therefore travels as a sentinel list with a
    ne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
2026-08-15 Pin shell scripts to LF so the UR magic file survives a checkout
    git reported it would convert datalogger/urmagic_acqlogger.sh to CRLF on the
    next checkout. That file is read by the robot controller's Linux shell, where
    a CRLF on the shebang line breaks the interpreter, so a fresh clone on a
    Windows workstation would ship a magic file that silently does nothing on
    insertion.
    Scope is deliberately narrow: only *.sh. The general absence of a line-ending
    policy is logged as F9 in erreur_hors_datalogger.md and stays out of this
    plan, since normalizing every tracked file would rewrite etalement.script and
    the golden fixture.
2026-08-15 Export the acquisition twin beside the untouched original
    generate_urscript_acq() and generate_urp_acq() build the base lines exactly
    as the existing pair does, pipe them through _build_acq_lines(), and write
    through the same _write_export(), so the hand-edit guard, the export-state
    digest and the PolyScope memory budget all apply to the acq twins too.
    _build_urscript_lines(), generate_urscript() and generate_urp() are not
    modified: the diff of export.py contains zero deleted lines, which is the
    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
2026-08-15 Add the on-robot acquisition daemon
    Stdlib-only, valid under Python 2.7 (the controller) and 3.13 (the tests),
    447 lines. Pure functions carry most of the surface: parse_ft_line,
    parse_sample_line, find_usb_mount, format_csv, next_free_name. FTReader and
    LogServer take their clock, output directory and sensor by injection, so a
    test needs no USB key, no wall clock and no FT-300. The CSV is written in
    binary with explicit newlines, flushed and fsynced, so the bytes a Windows
    test sees are the bytes the Linux controller writes.
    Fixes one seam the agent could not know about: the STOP amendment landed
    after it was dispatched, so the daemon treated the CB3 counting sentinel as
    an ordinary sample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
2026-08-16 Track the generated acquisition script for the student
    etalement_acq.script is the file loaded on the pendant for an instrumented
    trial, so it ships beside etalement.script rather than being regenerated on
    the student's machine. Same caveat as the original applies: F10 in
    erreur_hors_datalogger.md records that neither artifact states the cycle
    configuration that produced it.
2026-08-16 Prove the acq twin changes no motion, fix the ERR reply encoding
    tests/test_acq_export.py, 13 tests: the base line list is unchanged whether
    or not the acq wrapper runs, a headless export still equals the golden
    fixture byte for byte, and parse_poses returns the same 346 poses, cycle
    indices and in_contact flags for both scripts. Line numbers are excluded
    from that comparison on purpose, and the test says so: the thread definition
    is inserted above def etalement(), which shifts the final retreat move by 51
    lines while its pose is identical. Content checks assert the thread, the
    keep_logging flag, the bounds guard, the socket opened before motion, the
    STOP handshake after the retreat, the cou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
2026-08-16 Document the on-robot acquisition path and its deployment
    onrobot/README.md: what each of the three files is and where it runs, why
    the buffer and the file write cannot be in URScript on a CB3, the six-step
    deployment from USB insertion to CSV retrieval, the CSV format with the
    reason the Time column steps 0.016 and 0.024 alternately, the port-50100
    protocol table including the counting sentinel and why a CB3 needs one, the
    three-shell offline exercise through the emulator, how to run the two test
    suites, and five known limitations stated plainly rather than buried.
    datalogger/README.md: the status row for the main path flips to implemented
    and points at ../onrobot/, and the folder states t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
2026-08-16 Turn the reply-encoding test into a regression test, drop debug output
    The agent that wrote this suite surfaced the strict-ASCII _reply() defect
    and, per its instructions, left the test failing rather than touching the
    daemon. The daemon has since been fixed, so the test passes and its class
    name and docstring were saying the opposite. Renamed to
    ReplyEncodingRegressionTests and rewritten to describe the fixed behaviour
    and why the case is kept: the failure is invisible on an English-locale
    machine and would return the moment the encoding were tightened again. A
    leftover debug print is removed.
    Full suite: 154 tests, OK (4 skipped).
2026-08-16 Pin the settings freeze, state the line-ending policy (F4, F5, F9)
    F4: ur5_sim/config.py reads settings once at import and derives its
    constants there. That is deliberate - one process, one read, with the read
    time published by settings_summary() - and it is unchanged here. What was
    missing is a test saying so, since nothing failed if a later reader expected
    reload_settings() to move those constants. Three tests in
    test_sim_reads_settings.py now pin it, with the rationale in the assertion
    message.
    F5: the four dead artifacts are gone (etalement.script.bak,
    ur5_etalementv6.py.original, tcp_live.json, validate_etalement.py, the last
    a deprecated shim duplicating run_validate.py that nothing r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
2026-08-16 Correct two stale comments in viewer.py (F12)
    The visualize() docstring still described the retired tcp_live.json file
    exchange, whose file F5 has just deleted; it now names the UDP loopback
    mechanism that replaced it. A second comment pointed at
    meshes/TestMeasure.PNG while the tracked file is TestMeasure.png, which
    Windows resolves and a case-sensitive checkout would not.
    The second one is worth more than its size: the comment-resolution check
    added in tests/test_repo_hygiene.py passes on this machine precisely because
    the filesystem hides the defect, so the test is only as strong as the host it
    runs on. Noted in F12 with the stronger form, comparing against the
    case-sensitive tracked set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
2026-08-16 Validate settings on load and at export, fail the guard closed (F1, F3, F2, F13)
    F1, the one that could reach the robot. Settings loaded from
    etalement_settings.json were applied with a bare setattr and never checked,
    while validate() was called from a single place, the settings window's apply
    button. That file is gitignored, hand-editable and documented as such, so a
    value typed there bypassed every bound in SPECS: force_z_target is declared
    2 to 20 N and a file asking for 200 N produced a force_mode block demanding
    200 N against the plate, with no warning anywhere in the chain. Now from_file
    validates after applying overrides and, on any error, prints one line per
    faulty field and returns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
2026-08-16 Test the byte measurement and the four-generator validity gate (F2, F13)
    Seven tests, each looping over all four generators where it applies: no
    carriage return in any output, the size on disk equal to the measured
    content length, the budget verdict driven by bytes rather than by the host
    operating system, an invalid Settings refusing every generator while
    creating no file at all, force=True not bypassing validity while still
    bypassing the hand-edit guard, and a valid Settings still exporting through
    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
2026-08-17 State the remaining work at the top of the defect register
    The file had grown to fifteen entries with the status of each buried inside
    it, so finding what is still owed meant reading all of it. A table at the
    top now names the four: F15 open, F10 half done, F6 deferred by decision to
    the session that must reopen viewer.py anyway, F7 already scheduled as task
    6 of the emulator plan. Each line says who it waits on and why.
    Two corrections to the shared text while there. The Purpose section still
    claimed nothing here was fixed, which stopped being true after eleven of
    them were. And F10 carried no status line although only half of it was done:
    the decision was taken, the traceability half was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
2026-08-17 Make every export state what produced it, and recover the trial (F10)
    The committed etalement.script was an artifact nobody could regenerate. No
    export recorded the cycle configuration behind it, so a trial could not be
    reproduced, the artifact and the code could not be checked against each
    other, and any test written as "regenerate and compare" failed for reasons
    unrelated to the change under test. F11 shipped through exactly that gap.
    The configuration turned out to be recoverable rather than lost. Inverting
    the first waypoint back into the plate frame gives the radius directly, since
    x0 = 2R there, and y0 gives CIRC_Y_START; an exhaustive search over the two
    remaining integers pinned the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
2026-08-20 Add RTDE wire encoder with the byte layout pinned against the C monitor
2026-08-20 Interpolate the 20 Hz trajectory up to the 125 Hz controller rate
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2026-08-20 Move the RTDE wire layer out to respect the file-size ceiling
    rtde_server.py had grown to 570 lines (~6100 tokens) against the
    project's 4096-token-per-file ceiling because four consecutive
    implementation-plan tasks appended to it in turn. The package framing,
    output recipe, runtime-state machine, and trajectory sampling (pure
    helpers with no socket state) now live in ur5_sim/rtde_wire.py;
    rtde_server.py keeps RtdeServer and imports every moved name back by
    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
2026-08-20 Extract the viewer's playback clock so PAUSE has a tested contract
    The viewer's START/STOP timing lives in closures over a matplotlib
    figure, so the one rule the RTDE emulator depends on is untestable
    where it sits: a PAUSE must keep elapsed simulation time (same run,
    the monitor must not split the CSV) while a STOP must discard it
    (next START replays from frame 0).
    PlaybackClock states that rule on its own, with no matplotlib import,
    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
2026-08-20 Split viewer.py by concern to hold the file-size ceiling (F6)
    viewer.py was 917 lines (~9100 tokens) against the workspace ceiling of
    4096 tokens per source file, and the register requires the split BEFORE
    PAUSE is added to it, so the split and the feature are not one
    unreviewable diff.
    The seam was already half cut: mpl_display.py existed but nothing
    imported it, and it had drifted (no probe stars, legend built before the
    overlays instead of after). It is now the real panel builder, matching
    what viewer.py drew, plus the per-frame artist repaint. The rest went
    where it belonged:
    swift_scene.py scene lifecycle: setup, WebSocket keepalive, per-frame
    pose push (one cop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
2026-08-20 Mark a loopback endpoint as a simulated source in the CSV header
    Adapts Task 9 of the RTDE-emulator plan to the current
    format_csv_header, which F8 already changed to derive Data Source
    from local_addr at runtime instead of a hardcoded lab literal.
    format_csv_header gains a trailing simulated flag that prints a
    WARNING line when set; csv_open() derives it via the new
    is_loopback_ipv4(robot_ip), since the emulator binds 127.0.0.1 only
    and the real robot is at 192.168.4.38. csv_open() itself (F15's
    target) is untouched.
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2026-08-21 Keep the output of a divergent run instead of deleting it (F18)
    The --repeat gate added yesterday detected a run whose exit code or summary
    line differed from the first, printed that it differed, and then deleted every
    captured output file. It reported the existence of evidence and destroyed it in
    the same breath, which is worthless to the next session: the failing CHECK line
    and the [RTDE] messages that name the failing path were exactly what was lost.
    A diverging run's full stdout is now kept as mismatch_run_<N>.out, named on the
    console, gitignored, and cleared at the start of the next --repeat run.
    Verified against the stub gates: a run with an altered summary and a run with an
    altered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
2026-08-21 Log F17 and F18: F16's second source was never reproduced
    F17 records the measurement the professor asked for. Four campaigns: 100 runs
    of the harness on current code, all identical; 100 runs with F16's half-2 fix
    reverted, all identical; 2000 iterations of the NOT_FOUND scenario alone with
    the fix reverted, no reproduction and not one "stream lost"; and a concurrent
    campaign that does break the assertion but through MON_ERR_CONNECT, ephemeral
    ports exhausted by the stress driver itself, which the fixed variant reproduces
    just as readily. Roughly 82000 iterations, no instance of the mechanism F16
    blames.
    The evidence F16 quoted does not settle it either: both lines it cites are the
    expected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
